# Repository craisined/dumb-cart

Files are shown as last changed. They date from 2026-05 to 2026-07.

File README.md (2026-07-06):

# Dumb Cart 🚗

## Website Access

The website can currently be found https://opencart.craisin.tech, though this is tentative

## Install Cart Firmware 🧑‍💻

### CLI

Install the required board manager and libraries for XIAO ESP32C6:
```bash
arduino-cli config add board_manager.additional_urls https://espressif.github.io/arduino-esp32/package_esp32_index.json
arduino-cli core update-index
arduino-cli core install esp32:esp32
arduino-cli lib install "Encoder" "Seeed Arduino LSM6DS3" "Adafruit HX711"
```

Cinouke and upload binary, replacing `/dev/ttyACM0` with the path of the port the microcontroller is plugged into:
```bash
git clone https://github.com/craisined/dumb-cart.git
arduino-cli compile --fqbn esp32:esp32:XIAO_ESP32C6 client
arduino-cli upload -p /dev/ttyACM0 --fqbn esp32:esp32:XIAO_ESP32C6 client
```
### IDE

1. Go to **File → Preferences → Additional Board Manager URLs** and add https://espressif.github.io/arduino-esp32/package_esp32_index.json
2. Go to **Tools → Board → Board Manager** and download **esp32 by Espressif Systems**
3. Go to **Tools → Board** and select **XIAO_ESP32C6**
4. Go to **Tools → Manage Libraries** and install all the libraries in [libraries.md](documentation/libraries.md)
5. Open [client.ino](client/client.ino) and upload to the board

## Assemble Hardware 🔧

### Hardware

1. Print out [dumb_cart.gcode.3mf](cad/dumb_cart.gcode.3mf), retaining all the print settings (tested with pla)
2. Push in bearings
3. Screw in electronics
4. Push in axles, then screw wheels onto axles

### Electronics

#### Load Cell and ADC
Wire the screw connector as following:
- E+ → red
- E- → black
- A+ → green
- A- → white

If using the Adafruit ADC and a Grove Pigtail cable, solder the following connections:
- VIN → red
- GND → black
- DATA → yellow
- SCK → blue

#### Battery
Cut off the connector, then solder:
- \+ contact → red
- \- contact → black

#### Connections
- ADC → D8/D9 port
- Accelerometer → any I2C port (D4/D5)
- Optical encoder → D2/D3 port

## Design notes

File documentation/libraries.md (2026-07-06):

# Libraries 📚

## Arduino Libraries 🚗

- https://github.com/adafruit/Adafruit_HX711
- https://github.com/paulstoffregen/encoder
- https://github.com/Seeed-Studio/Seeed_Arduino_LSM6DS3

## Frontend Libraries 💻

- https://www.chartjs.org/
- https://www.chartjs.org/chartjs-plugin-zoom/latest/guide/

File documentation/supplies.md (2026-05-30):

# Supplies 🔧

## Electronics ⚡

### Preferred
- [Accelerometer & Gyroscope](https://www.seeedstudio.com/Grove-6-Axis-Accelerometer-Gyroscope.html)
- [ADC](https://www.seeedstudio.com/Grove-ADC-for-Load-Cell-HX711-p-4361.html)
- [Battery](https://www.adafruit.com/product/328)
- [Expansion Board](https://www.seeedstudio.com/Grove-Shield-for-Seeeduino-XIAO-p-4621.html)
- [Load Cell](https://www.adafruit.com/product/4540)
- [Microcontroller](https://www.seeedstudio.com/Seeed-Studio-XIAO-ESP32C6-p-5884.html)
- [Optical Encoder](https://www.seeedstudio.com/Grove-Optical-Rotary-Encoder-TCUT1600X01.html)

### Replacements
- [ADC](https://www.adafruit.com/product/5974) (requires [Grove pigtail cables](https://www.adafruit.com/product/5244))

## Physical Parts 🔧
- [Ball Bearings](https://a.co/d/02ownwvs)

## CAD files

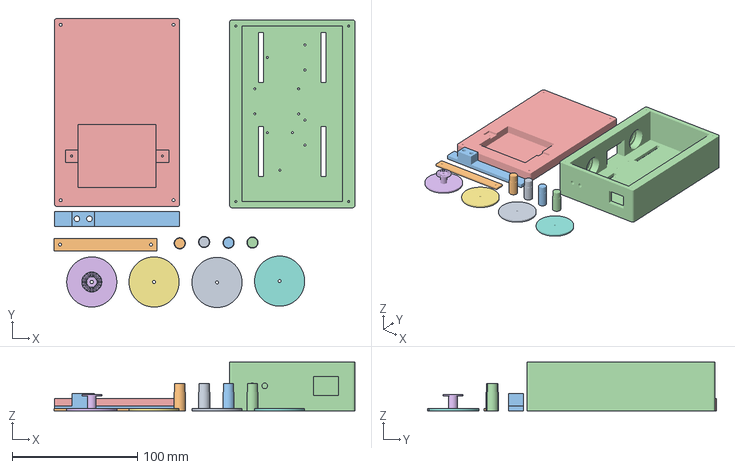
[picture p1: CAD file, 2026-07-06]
cad/dumb_cart.3mf
240.2 x 230.6 x 39.0 mm

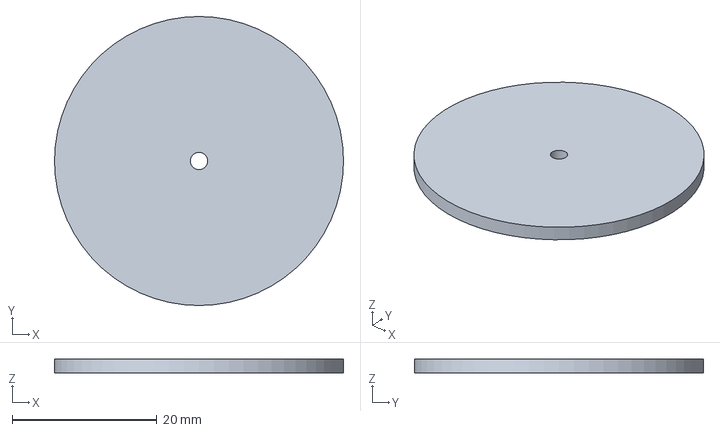
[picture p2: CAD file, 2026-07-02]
cad/wheel.FCStd
40.0 x 40.0 x 2.00 mm

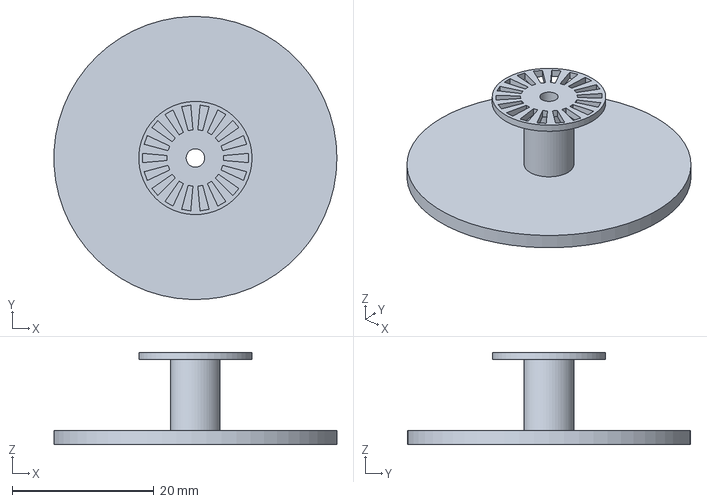
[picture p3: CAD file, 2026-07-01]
cad/encoder_wheel.FCStd
40.0 x 40.0 x 13.0 mm

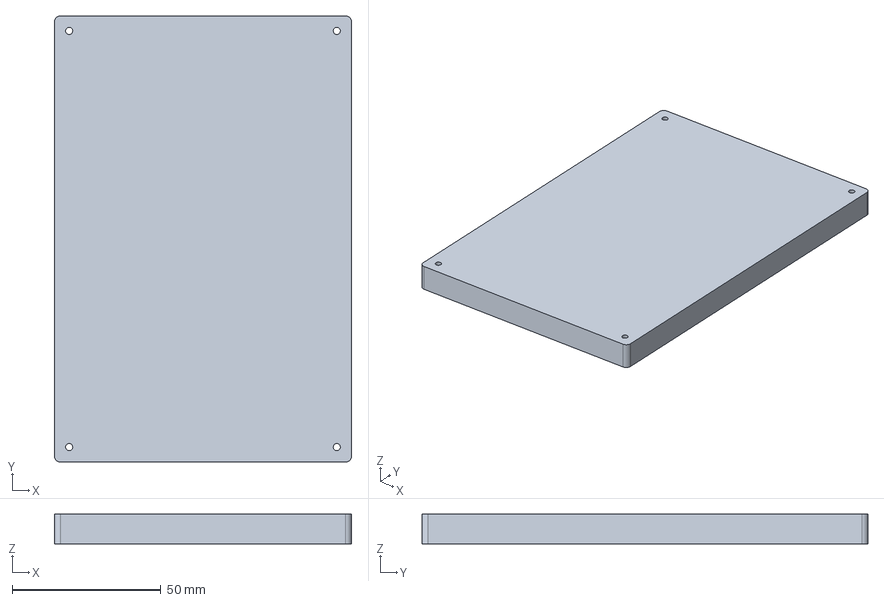
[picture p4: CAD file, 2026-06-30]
cad/cart_top.FCStd
100.0 x 150.0 x 10.0 mm

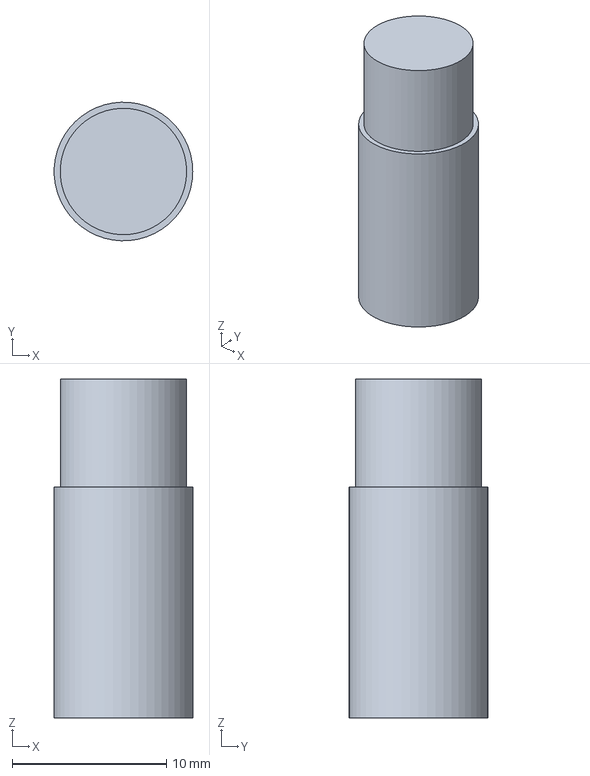
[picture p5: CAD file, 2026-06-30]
cad/axle.FCStd
8.99 x 9.00 x 22.0 mm

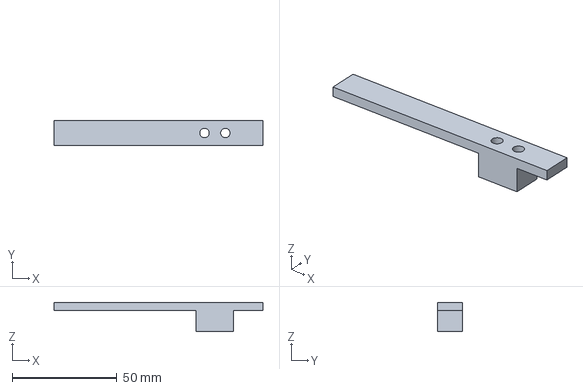
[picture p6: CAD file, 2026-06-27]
cad/bumper.FCStd
100.0 x 12.0 x 14.0 mm

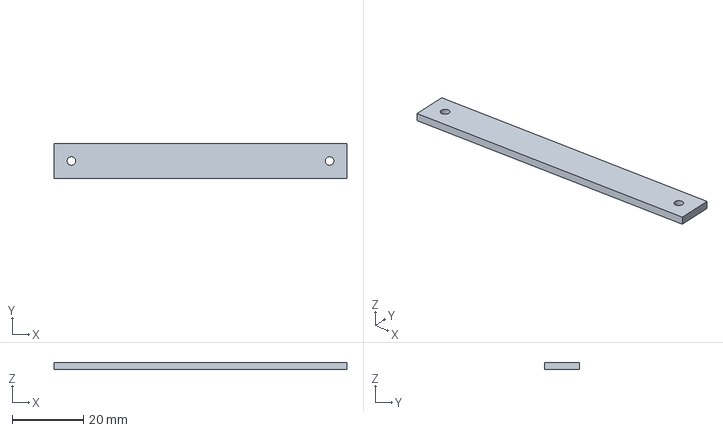
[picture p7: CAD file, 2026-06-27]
cad/battery_holder.FCStd
82.3 x 9.80 x 2.00 mm

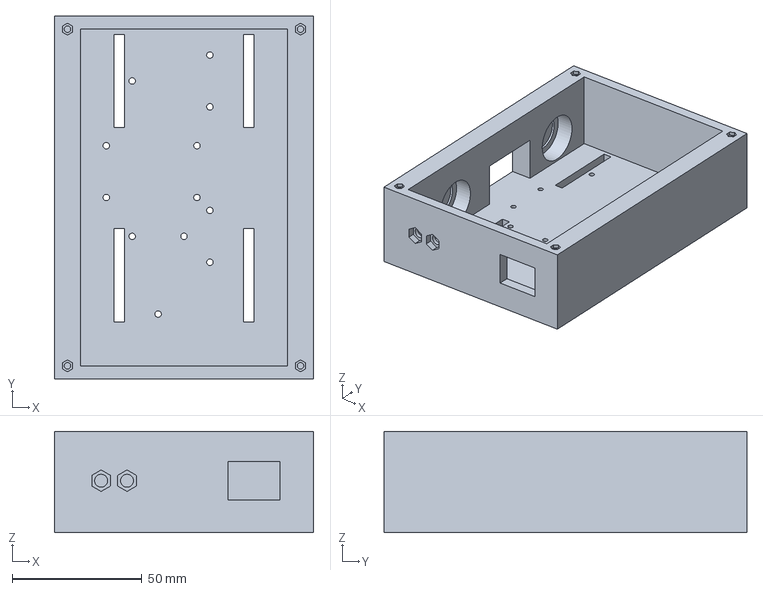
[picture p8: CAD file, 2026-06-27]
cad/cart_bottom.FCStd
100.0 x 140.0 x 39.0 mm

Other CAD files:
cad/dumb_cart.gcode.3mf

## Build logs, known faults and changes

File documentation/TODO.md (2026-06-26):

# TODO

## Cart Code
- Aquire parts ✅
- Get parts working ✅
- Test BLE ✅
- Connect BLE to parts ✅
- Final revision ✅

## Modeling
- Aquire parts ✅
- Design layout ✅
- Create initial CAD ✅
- Assembly
- Final revision

## Website
- Design website visuals ✅ (ish but good enough for now)
- Create chart.js chart ✅
- Connect chart to BLE
    - Conenct website to BLE ✅
- Connect website controls to chart
- Final revision

- Trials
- Selection
- Import/export csv
- Multi cart support

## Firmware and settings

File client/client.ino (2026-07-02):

#include <Adafruit_HX711.h>
#include <BLEDevice.h>
#include <BLEUtils.h>
#include <BLEServer.h>
#include <BLE2901.h>
#include <BLE2902.h>
#include <Encoder.h>
#include <LSM6DS3.h>
#include <Wire.h>

const float gravity = 9.81;
const float pi = 3.14;
const float meter_per_ticks = (0.04 * pi) / (18 * 4);
const float newtons_per_ticks = (0.33 * gravity) / 63720; // measured by ito en

// accelerometer attaches to I2C slot, load cell attaches to A0/D0 slot, encoder attaches to UART slot
const uint8_t accelerometer_addr = 0x6A;
const uint8_t load_cell_data_pin = D9;
const uint8_t load_cell_clock_pin = D8;
const uint8_t encoder_pin_1 = D3;
const uint8_t encoder_pin_2 = D2;

LSM6DS3 accelerometer(I2C_MODE, accelerometer_addr);
Adafruit_HX711 load_cell(load_cell_data_pin, load_cell_clock_pin);
Encoder encoder(encoder_pin_1, encoder_pin_2);

typedef struct{
    float acceleration;
    float force;
    float distance;
    int time;
} Sensors;
Sensors sensors;

const String service_uuid = "907da526-6f31-42c6-8b17-4fa0c76ad1d7";
const String sensor_characteristic_uuid = "383dfe4a-06d1-49bc-862f-06841d591a7e";
bool device_connected = false;

BLEServer *server_ptr;
BLEService *service_ptr;
BLECharacteristic *sensor_characteristic_ptr;
BLEAdvertising *advertising_ptr;

int last_send = 0;

class CartServerCallbacks: public BLEServerCallbacks {
    void onConnect(BLEServer* server_ptr) {
        Serial.println("Device Connected");
        device_connected = true;
    };

    void onDisconnect(BLEServer* server_ptr) {
        Serial.println("Device Disconnected");
        device_connected = false;
        server_ptr->getAdvertising()->start();
    }
};

void begin_sensors(){
    accelerometer.begin();
    load_cell.begin();
    for (uint8_t t=0; t<3; t++) {
        load_cell.tareA(load_cell.readChannelRaw(CHAN_A_GAIN_128));
    }
}

void create_characteristic(BLECharacteristic* &characteristic_ptr, String characteristic_uuid, String description){
    characteristic_ptr = service_ptr->createCharacteristic(
        characteristic_uuid,
        BLECharacteristic::PROPERTY_READ | BLECharacteristic::PROPERTY_NOTIFY
    );
    BLE2901 *descriptor_ptr = new BLE2901();
    descriptor_ptr->setDescription(description);
    descriptor_ptr->setAccessPermissions(ESP_GATT_PERM_READ);
    characteristic_ptr->addDescriptor(descriptor_ptr);
    characteristic_ptr->addDescriptor(new BLE2902());
}

void begin_bluetooth(){
    BLEDevice::init("Dumb Cart");
    server_ptr = BLEDevice::createServer();
    server_ptr->setCallbacks(new CartServerCallbacks());
    service_ptr = server_ptr->createService(service_uuid);
    create_characteristic(sensor_characteristic_ptr, sensor_characteristic_uuid, "Sensors");
    service_ptr->start();
    advertising_ptr = BLEDevice::getAdvertising();
    advertising_ptr->addServiceUUID(service_uuid); 
    advertising_ptr->setScanResponse(true);
    BLEDevice::startAdvertising();
}

void update_sensors(){
    sensors.acceleration = accelerometer.readFloatAccelX() * gravity;
    sensors.force = load_cell.readChannelBlocking(CHAN_A_GAIN_128) * newtons_per_ticks;
    sensors.distance = encoder.read() * meter_per_ticks;
    sensors.time = millis();
}

void update_bluetooth(){
    sensor_characteristic_ptr->setValue((uint8_t*)&sensors, sizeof(sensors));
    sensor_characteristic_ptr->notify();
}

void setup() {
    Serial.begin(9600);
    begin_sensors();
    begin_bluetooth();
}

void loop() {
    update_sensors();
    if (millis() - last_send > 100){
        update_bluetooth();
        last_send = millis();
    }
}

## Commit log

2026-04-07 esp32 test
2026-04-07 shift client before esp32 stuff works
2026-04-08 sample arduino test
2026-04-14 bluetooth samples
2026-05-23 put sensors in a class
2026-05-26 change filter
2026-06-02 add fcstd and get btns
    [cart_top.FCStd]
2026-06-02 start cart bottom
    [cart_bottom.FCStd]
2026-06-02 screwholes for bottom cad
    [cart_bottom.FCStd]
2026-06-03 html + sm cad stuff
    [cart_bottom.FCStd, cart_top.FCStd]
2026-06-03 functioning tabs
    [cart_bottom.FCStd, cart_top.FCStd]
2026-06-03 update cart size
    [cart_bottom.FCStd, cart_top.FCStd]
2026-06-03 fix filet
    [cart_bottom.FCStd, cart_top.FCStd]
2026-06-04 minor export button adjustments + export code for png & jpg
2026-06-08 new cart
    [cart_bottom.FCStd, cart_top.FCStd]
2026-06-08 add cad files
    [cart_bottom.FCStd, encoder.FCStd]
2026-06-08 add load cell to front
    [cart_bottom.FCStd]
2026-06-08 cart thing
    [cart_bottom.FCStd]
2026-06-08 chart and shi
    [cart_bottom.FCStd]
2026-06-11 cad russian doll procrastination shits
    [cart_bottom.FCStd, encoder.FCStd]
2026-06-11 upd cad
    [axle.FCStd, battery_holder.FCStd, cart_bottom.FCStd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]
2026-06-11 bumper, naming, and FAAAAH
    [axle.FCStd, battery_holder.FCStd, bumper.FCStd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]
2026-06-11 fix ports and shit
    [client.ino]
2026-06-11 basic chart functionality
    [battery_holder.FCStd, bumper.FCStd, cart_bottom.FCStd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]
2026-06-16 zoom buttons done :D
2026-06-20 fixed tab switching crash
2026-06-20 Pan & selection switch
2026-06-27 Update CAD to use holes
    [axle.FCStd, battery_holder.FCStd, cart_bottom.FCStd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]
2026-06-27 update cad to use model inserts
    [axle.FCStd, battery_holder.FCStd, bumper.FCStd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]
2026-06-30 tooltip + cad stuffs
    [encoder_wheel.FCStd, wheel.FCStd]
2026-06-30 elongate cart for wheels
    [axle.FCStd, cart_top.FCStd]
2026-06-30 encoder start pos
2026-07-01 cad + styling
    [encoder_wheel.FCStd, wheel.FCStd]
2026-07-02 calibrate stuff
2026-07-06 update readme and add print files
    [dumb_cart.3mf, dumb_cart.gcode.3mf]
